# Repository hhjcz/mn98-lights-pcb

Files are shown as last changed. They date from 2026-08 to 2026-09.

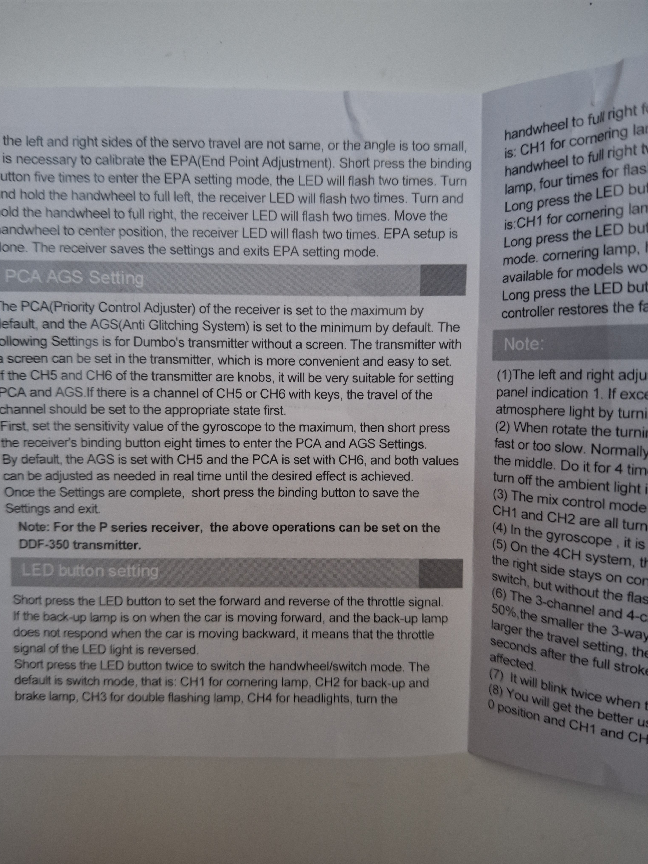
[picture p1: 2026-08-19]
docs/p6dc-led-button-settings-1.jpg

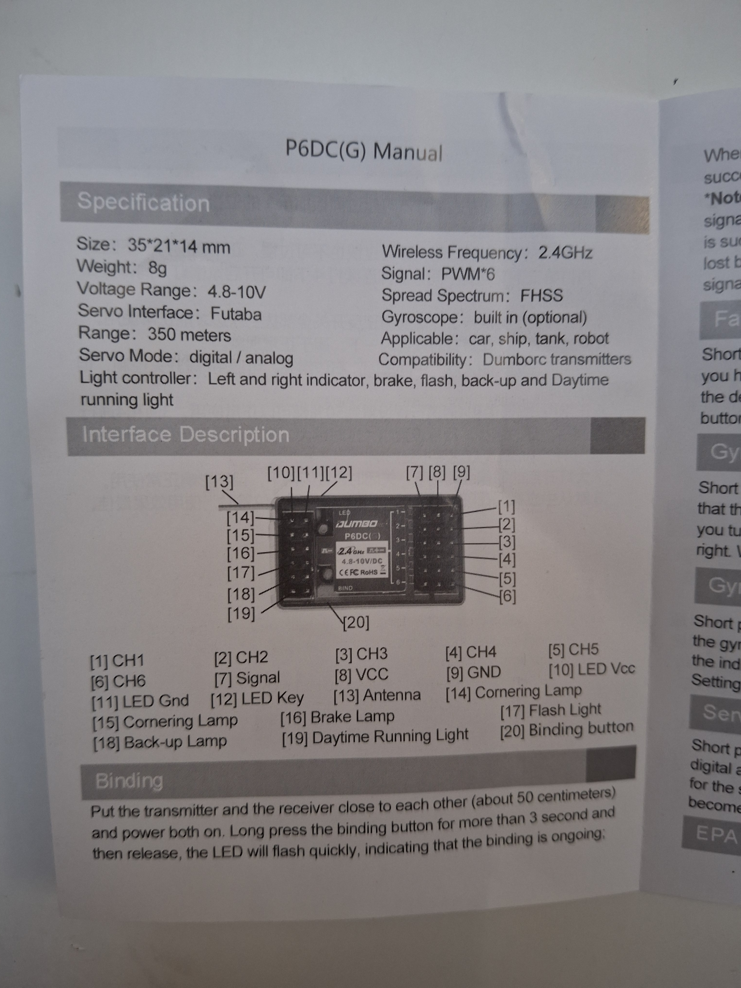
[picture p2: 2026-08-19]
docs/p6dc-interface-description.jpg

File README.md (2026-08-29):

# MN98 Lights PCB

Passive body-light distribution boards for the MN98 RC car and DumboRC P6DC
receiver. The P6DC already controls the LEDs, so variants in this repository
must not add transistors, MOSFETs, resistors, regulators, capacitors, or GND.

## Shared P6DC Interface

The receiver manual is in `docs/`. The light channels follow the P6DC physical
output order: left cornering, right cornering, brake, flash, back-up, and
daytime running light. Any detachable body-to-chassis cable must preserve that
order without crossed conductors.

Before connecting a body harness, confirm LED polarity with a meter. Do not
infer it from wire colours or connector orientation.

## Archived JST-PH Variant

`v1.0-jst-ph/` contains the original JST-PH work-in-progress, including its
KiCad project, Gerbers, PDFs, connector-specific documentation and skill.
It is preserved as a reference and must not be overwritten by the next design.

## Dupont Body Distributor

`pcb-svetla-mn98.kicad_sch` and `pcb-svetla-mn98.kicad_pcb` are the first
compact passive body-side distributor. The current placement candidate is
32 x 36 mm, within the verified 40 x 50 mm maximum envelope. It uses two
merged right-angle 2.54 mm male headers for paired Dupont LEDs. The left header
contains LEFT TURN and DRL. The right header contains RIGHT TURN, BRAKE,
BACK-UP, MARKER, RAMP and SPARE. Both JST-PH body-link connectors exit left so
their harnesses run toward the same chassis location.
All connector courtyards are inside the board outline. Routing is intentionally
deferred until the mechanical placement and JST-PH orientation are approved.
The JST-PH courtyards are inset 2.5 mm from the left edge to protect the
connectors and leave board material around their through-hole pads.

| Header | Physical pairs, top to bottom |
| --- | --- |
| J1, 1x4 | `COMMON+ / LEFT`, `COMMON+ / DRL` |
| J2, 1x12 | `COMMON+ / RIGHT`, `COMMON+ / BRAKE`, `COMMON+ / BACK-UP`, `COMMON+ / MARKER`, `COMMON+ / RAMP`, `COMMON+ / SPARE` |

JP1, JP2 and JP3 select `DRL` or `FLASH` respectively for MARKER, RAMP and
SPARE. Fit the shunt across pins 1-2 for DRL, or 2-3 for FLASH. All right-angle
connectors face outward from the board. The headers are intentionally unkeyed:
silkscreen marks the common-positive side of every pair. Confirm the supplied
LED pair polarity before connecting power.

### Body Link

The detachable body link uses two right-angle JST-PH 1x4 THT connectors. Pin 1
is `COMMON+` on both connectors, so swapping cables A and B cannot connect a
signal output to common positive; it only exchanges light functions.

| Connector | Pin 1 | Pin 2 | Pin 3 | Pin 4 |
| --- | --- | --- | --- | --- |
| J14, link A | `COMMON+` | `LEFT` | `RIGHT` | `BRAKE` |
| J15, link B | `COMMON+` | `FLASH` | `BACK-UP` | `DRL` |

Use pin-to-pin female-female harnesses. A practical custom-length harness can
be made from two pre-crimped JST-PH 4-pin pigtails joined wire-for-wire. Verify
continuity and pin order with a meter before connecting the receiver.

### Planned P6DC Adapter

A second passive PCB will plug into the six 2-pin P6DC light outputs through a
2x6 Dupont female socket and expose matching J14/J15 JST-PH connectors. It
will join the P6DC common-positive pins and preserve the pinout above. The
adapter is intentionally deferred until its fit against the receiver has been
measured. Both designs may later share one customer-panel PCB for fabrication.

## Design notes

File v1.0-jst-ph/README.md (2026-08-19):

# MN98 light distribution PCB

Passive 30 x 40 mm, two-layer FR-4 adapter for the MN98 body lighting and
DumboRC P6DC. The board contains no active components and has no GND net.

## Input J14

J14 is an 8-position right-angle JST-PH connector. Pin 1 is marked on the
footprint. P6DC wiring is:

| Pin | Net |
| --- | --- |
| 1 | COMMON+ |
| 2 | COMMON+ |
| 3 | LEFT |
| 4 | RIGHT |
| 5 | BRAKE |
| 6 | FLASH |
| 7 | BACK-UP |
| 8 | DRL |

Pins 1 and 2 are connected to the same 1.2 mm common-positive spine. LED
connector pad 1 is COMMON+ and pad 2 is the controlled P6DC channel.

Pins 3--8 follow the top-to-bottom order of the P6DC light outputs in the
manual: P6DC [14] left cornering, [15] right cornering, [16] brake, [17]
flash, [18] back-up, and [19] daytime running light. Terminate the chassis
cable as J14 pin-to-pin; do not reverse its conductor order between plugs.

## LED outputs

| Connector | Function | Controlled net |
| --- | --- | --- |
| J1 | Left front turn | LEFT |
| J2 | Right front turn | RIGHT |
| J3 | Left rear turn | LEFT |
| J4 | Right rear turn | RIGHT |
| J5 | Spare | FLASH |
| J6 | Left 5 mm headlight | DRL |
| J7 | Left 3 mm marker | MARKER via JP1 |
| J8 | Left rear red | REAR_RED via JP2 |
| J9 | Roof ramp | RAMP via JP3 |
| J10 | Right 5 mm headlight | DRL |
| J11 | Right 3 mm marker | MARKER via JP1 |
| J12 | Right rear red | REAR_RED via JP2 |
| J13 | Spare | DRL |

All J1--J13 are right-angle JST-PH S2B-PH-K footprints.

## Jumper settings

JP1 and JP3 are 1x03 headers. Fit one 2.54 mm shunt between the centre pin
and the selected outside pin.

| Jumper | Left position | Right position |
| --- | --- | --- |
| JP1 | DRL -> MARKER | MARKER -> FLASH |
| JP3 | DRL -> RAMP | RAMP -> FLASH |

JP2 is a 2x03 header. Fit one vertical 2.54 mm shunt in the column labelled
DRL, BRAKE, or BACK-UP to connect that channel to both rear-red connectors.

## Before manufacturing

1. Check that 30 x 40 mm fits the exact available MN98 body cavity.
2. Check the mating housing and the actual pin-1/polarity of every MN98 LED
   lead. Do not infer it from lead colours or connector orientation.
3. Open `pcb-svetla-mn98.kicad_pcb` in KiCad PCB Editor, run DRC, and resolve
   the two JP2 ratsnest indicators before ordering. The generated Gerbers are
   an inspection aid, not a released fabrication package.

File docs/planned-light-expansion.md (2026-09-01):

# Planned Light Expansion

> **DRAFT / UNVERIFIED**
>
> This document records ideas for a possible future revision. It is not the
> electrical specification of the current PCB. Do not update the schematic,
> PCB placement, routing, silkscreen, or manufacturing files from this document
> until the relevant measurements and decisions below are complete.

## Purpose

The current body distributor predates two purchased modules that may simplify
the chassis-to-body connection and add independently controlled auxiliary
lights. This draft preserves the proposed architecture and the assumptions that
must be tested when the modules arrive.

The intended future revision would:

- replace the planned custom P6DC adapter with a purchased six-wire adapter;
- omit the P6DC FLASH output, which is a true strobe function not currently
  needed on the MN98;
- use semantic body-light names instead of names copied from the P6DC manual;
- allow ROOF LIGHT to follow HEADLIGHTS or switch port 1;
- allow FRONT MARKER and SPARE to follow HEADLIGHTS or switch port 2;
- reserve one optional through-hole series-resistor position for each of those
  three outputs;
- remain a passive PCB containing only connectors, copper routing, labels,
  solder-select jumpers, and any explicitly approved series resistors.

The committed 32 x 36 mm placement-only design remains the active design until
this draft is verified and explicitly approved for a new placement revision.

## Purchased Modules

### Six-wire P6DC light adapter

Product page:

<https://www.aliexpress.com/item/1005008835970185.html>

Observed before delivery:

- the body-side connector appears to be a six-pin JST-PH connector;
- the adapter appears to use six conductors and omit FLASH;
- the likely functions are COMMON+, LEFT, RIGHT, TAIL/BRAKE, REVERSE, and
  HEADLIGHTS, but their physical order and polarity are not known.

The connector series, pin 1, conductor order, continuity, and polarity must all
be checked on the delivered part. The listing is not sufficient evidence for
an electrical pinout.

### DumboRC CH3 light controller

Product page:

<https://www.aliexpress.com/item/1005005666804975.html>

Installation video showing the same type of module:

<https://www.youtube.com/watch?v=yQgD09w_WAs>

Video demonstrating the two outputs and seven-state sequence:

<https://www.youtube.com/watch?v=6RompNNfQf8>

Local reference images copied from the product listing:

- [`ddf350-3ch-switch-overview.webp`](ddf350-3ch-switch-overview.webp)
- [`ddf350-3ch-switch-modes.webp`](ddf350-3ch-switch-modes.webp)
- [`ddf350-3ch-switch-jr-input.webp`](ddf350-3ch-switch-jr-input.webp)
- [`ddf350-3ch-switch-dimensions.webp`](ddf350-3ch-switch-dimensions.webp)
- [`ddf350-3ch-switch-output.webp`](ddf350-3ch-switch-output.webp)
- [`ddf350-3ch-switch-angle.webp`](ddf350-3ch-switch-angle.webp)

The listing calls this a `3CH LED Light Controller`, while the installation
video calls it a `Ch3 Light Control Module`. The latter interpretation is much
more consistent with the visible wiring: the controller is intended for the
receiver's CH3 output rather than providing three independently controlled LED
channels.

The listing and video show:

- one three-wire female JR receiver lead;
- one four-pin 2.54 mm male output, apparently arranged as two 2-pin LED ports;
- an approximately 24 x 10 mm controller body;
- approximately 120 mm overall length including the receiver lead;
- advertised on, off, breathing, and flashing effects.

The second video provides stronger evidence that the four pins are two
separately controlled 2-pin LED outputs:

```text
SWITCH PORT 1: + / -
SWITCH PORT 2: + / -
```

The ports are not fully independent because one receiver input cycles through a
fixed sequence, but the sequence can activate port 1 alone, port 2 alone, or
both ports. Treat them as `SW1+ / SW1-` and `SW2+ / SW2-`. Neither physical pin
order nor the electrical topology is verified on the delivered unit. The
photographs and videos must not be used as the final pinout. The controller may
use low-side switching, protection components, current regulation, or a supply
path that makes either positive output unsuitable for direct connection to
P6DC COMMON+.

The module has one PWM receiver input. The demonstrated controller advances
through seven output states when that input is clicked:

| State | Port 1 | Port 2 |
| --- | --- | --- |
| 1 | steady | off |
| 2 | slow pulse | off |
| 3 | off | steady |
| 4 | off | slow pulse |
| 5 | steady | steady |
| 6 | slow pulse | slow pulse |
| 7 | random flashing | random flashing |

The delivered unit must still be tested because firmware variants may use a
different order or behaviour.

## Proposed Light Names

Future PCB silkscreen should use the function on the vehicle:

| PCB label | Intended function | Probable source |
| --- | --- | --- |
| `LEFT TURN` | Left indicators | P6DC left output |
| `RIGHT TURN` | Right indicators | P6DC right output |
| `HEADLIGHTS` | Main front lights | P6DC DRL output |
| `TAIL / BRAKE` | Rear low-intensity tail and high-intensity brake | P6DC brake output |
| `REVERSE` | Reverse lights | P6DC back-up output |
| `FRONT MARKER` | Front marker lights | HEADLIGHTS or switch port 2 |
| `ROOF LIGHT` | Roof light bar | HEADLIGHTS or switch port 1 |
| `SPARE` | Future auxiliary light | HEADLIGHTS or switch port 2 |

The probable P6DC mapping is based on observed behaviour discussed during
planning. It must be checked across every P6DC light mode before becoming part
of the schematic specification.

## Preferred Electrical Architecture

The preferred architecture assumes that the P6DC light common positive,
receiver supply positive, switch port 1 positive, and switch port 2 positive
are the same electrical rail.

```text
Purchased P6DC adapter, 6 wires
  COMMON+ ----------------------+---------------- standard light positives
  LEFT -------------------------+---------------- LEFT TURN negative
  RIGHT ------------------------+---------------- RIGHT TURN negative
  TAIL/BRAKE -------------------+---------------- TAIL / BRAKE negative
  REVERSE ----------------------+---------------- REVERSE negative
  HEADLIGHTS -------------------+---------------- HEADLIGHTS negative
                                |
CH3 switch, two output ports    |
  SW1+ -------------------------+  only if verified as the same rail
  SW1- ---------------------------- roof selector
  SW2+ -------------------------+  only if verified as the same rail
  SW2- --------+------------------- marker selector
                +------------------- spare selector
```

With a verified shared positive rail, only the switched negative conductor of
each optional light needs selection:

```text
ROOF +   ------------------------------ COMMON+
ROOF -   -- R_ROOF -- [ HEADLIGHTS- | SW1- ]

MARKER + ------------------------------ COMMON+
MARKER - -- R_MARKER -- [ HEADLIGHTS- | SW2- ]

SPARE +  ------------------------------ COMMON+
SPARE -  -- R_SPARE -- [ HEADLIGHTS- | SW2- ]
```

This gives the following intended configurations:

| Output | Default or simple source | Alternate switch source |
| --- | --- | --- |
| `ROOF LIGHT` | `HEADLIGHTS` | `SWITCH PORT 1` |
| `FRONT MARKER` | `HEADLIGHTS` | `SWITCH PORT 2` |
| `SPARE` | `HEADLIGHTS` | `SWITCH PORT 2` |

FRONT MARKER and SPARE operate together when both select switch port 2. Their
combined current must remain within port 2's measured safe capacity. ROOF LIGHT
uses port 1 and can be activated separately in the demonstrated sequence.

TAIL/BRAKE is intentionally not a proposed FRONT MARKER source. Connecting the
front markers to that output would make them change intensity when braking,
which is not the intended vehicle behaviour.

Each three-pad selector must have unambiguous silkscreen showing the two valid
bridges. Simultaneously bridging both sides would connect two controlled
outputs and must be treated as an invalid configuration.

## Safe Fallback Architecture

If the two positive outputs are not proven to be the same rail, do not connect
them. ROOF LIGHT, FRONT MARKER, and SPARE must then use two-pole source
selection so both LED conductors move together between sources.

```text
HEADLIGHTS +  [ ]-[ ROOF + ]-[ ]  SW1+
HEADLIGHTS -  [ ]-[ ROOF - ]-[ ]  SW1-

HEADLIGHTS +  [ ]-[ MARKER + ]-[ ] SW2+
HEADLIGHTS -  [ ]-[ MARKER - ]-[ ] SW2-

HEADLIGHTS +  [ ]-[ SPARE + ]-[ ]  SW2+
HEADLIGHTS -  [ ]-[ SPARE - ]-[ ]  SW2-
```

This fallback needs six three-pad solder selectors instead of three. Both rows
for one light must always be set to the same side. Crossed or double-bridged
settings are invalid and could connect the P6DC and switch outputs together.
The corresponding `R_ROOF`, `R_MARKER`, or `R_SPARE` position remains in series
with each load after its two-pole selector.

The fallback remains the required design assumption until the common-positive
tests pass.

## Optional Series Resistors

The controller's 5-6 V open-circuit output does not prove whether it includes
LED current regulation. Do not add a resistor value based on that voltage
alone. Measure the output current-versus-load characteristic and inspect each
light assembly for an existing resistor.

The proposed PCB should nevertheless reserve three independent horizontal THT
positions:

```text
Resistor_THT:R_Axial_DIN0207_L6.3mm_D2.5mm_P10.16mm_Horizontal
```

| Position | Load |
| --- | --- |
| `R_ROOF` | ROOF LIGHT |
| `R_MARKER` | FRONT MARKER |
| `R_SPARE` | SPARE |

Fit a calculated resistor only when the selected light and source require it.
Fit a 0-ohm THT link or insulated wire link when current limiting already exists
in the controller or light assembly. An unused output may remain open.

FRONT MARKER and SPARE need separate resistor positions even though they share
switch port 2. A single resistor before the split would make their brightness
and current depend on whether one or both loads are connected.

Adding these optional resistors would intentionally revise the current project
rule that prohibits resistors. Do not change the skill or active schematic
until measurements show that the positions are useful and this scope change is
explicitly approved.

## Connector Plan

The connector plan is provisional:

- one six-pin JST-PH input for the purchased P6DC light adapter, subject to
  physical connector and pinout verification;
- one 1x4 2.54 mm female Dupont socket for the CH3 switch's two separate
  2-pin output ports;
- existing unkeyed two-pin Dupont body-light outputs with a visible `+` mark.

The switch can potentially plug directly into the PCB socket. Placement must
reserve clearance for its approximately 24 x 10 mm body, heat-shrink sleeve,
and receiver cable. Direct mounting must not use the switch pins as the only
mechanical support where vibration can fatigue them.

An alternative is a short four-wire extension. In that case the PCB connector
gender depends on the selected cable, so the final footprint should not be
chosen before deciding whether the module is direct-mounted or cable-mounted.

## DDF-350 Control Plan

The CH3 switch should connect to one unused P6DC receiver channel. The DDF-350
must generate whatever single-channel PWM command sequence the module expects.

Possible behaviours include:

- a short transition to an endpoint acting as a button press;
- sequential state changes on repeated button transitions;
- the seven-state sequence documented above;
- a different sequence in another firmware revision.

The ports are separately addressable only through the controller's fixed state
sequence; they are not two freely assignable receiver channels. Transmitter
buttons, switches, endpoints, and mixes should be configured only after
recording the delivered controller's actual state machine.

## Verification Procedure

### Safety

- Perform resistance and continuity measurements only with all power removed.
- Start powered tests with a current-limited supply where practical.
- Do not connect the two candidate positive rails together merely to test
  whether they are compatible.
- Test with inexpensive LEDs or an appropriate dummy load before connecting
  the vehicle light sets.
- Verify every unkeyed connector orientation and LED polarity with a meter.

### Six-wire adapter pinout

Record the actual pin numbering from the connector's mating face, not from the
cable side.

| Pin | Wire colour | P6DC connection | Measured function | Verified |
| --- | --- | --- | --- | --- |
| 1 | TBD | TBD | TBD | no |
| 2 | TBD | TBD | TBD | no |
| 3 | TBD | TBD | TBD | no |
| 4 | TBD | TBD | TBD | no |
| 5 | TBD | TBD | TBD | no |
| 6 | TBD | TBD | TBD | no |

Confirm that FLASH is absent rather than silently combined with another
function.

### CH3 switch pinout

Record pin order from a clearly identified end of the four-pin header.

| Pin | PCB marking | Continuity | Observed output | Verified |
| --- | --- | --- | --- | --- |
| 1 | TBD | TBD | TBD | no |
| 2 | TBD | TBD | TBD | no |
| 3 | TBD | TBD | TBD | no |
| 4 | TBD | TBD | TBD | no |

Check the JR lead separately:

| JR conductor | Expected role | Verified role |
| --- | --- | --- |
| Black | GND | TBD |
| Red | Receiver supply positive | TBD |
| White | PWM signal | TBD |

### Common-positive decision gate

The preferred single-pole selectors are allowed only after all of these checks
pass:

1. Both switch output positives have near-zero resistance to JR red with the
   module unpowered.
2. The two switch output positives have near-zero resistance to each other.
3. P6DC light COMMON+ has near-zero resistance to receiver supply positive with
   the receiver unpowered.
4. All candidate positives measure the same voltage relative to receiver GND
   when powered.
5. The voltage difference remains negligible under representative LED load and
   in every relevant light mode.
6. No diode, regulator, current limiter, or protected output separates any
   positive from the receiver supply rail.
7. Supplying one connection cannot back-power a module through an output in an
   undocumented way.

If any check fails or remains ambiguous, use the two-pole fallback and keep the
positive rails separate.

### Switch behaviour matrix

First record the state after power-up and after signal loss. Then test stable
endpoint positions, short endpoint pulses, repeated pulses, and held commands.

| Input action or state | Port 1 | Port 2 | Persists after neutral | Notes |
| --- | --- | --- | --- | --- |
| Power on | TBD | TBD | TBD | |
| First click | expected steady | expected off | TBD | |
| Second click | expected slow pulse | expected off | TBD | |
| Third click | expected off | expected steady | TBD | |
| Fourth click | expected off | expected slow pulse | TBD | |
| Fifth click | expected steady | expected steady | TBD | |
| Sixth click | expected slow pulse | expected slow pulse | TBD | |
| Seventh click | expected random flash | expected random flash | TBD | |
| PWM signal removed | TBD | TBD | TBD | |
| Power cycled | TBD | TBD | TBD | |

Identify steady on, steady off, breathing, flashing, and any sequence
dependency. Confirm which states operate only one port and whether the previous
state is retained after a power cycle.

### Switch current-limiting test

Test each port separately in its steady-on state using known resistive loads.
Start with a high resistance and decrease it cautiously while recording voltage
and calculated current. Do not short the output.

| Load | Voltage | Calculated current | Port | Notes |
| --- | --- | --- | --- | --- |
| 1 kohm | TBD | TBD | TBD | |
| 470 ohm | TBD | TBD | TBD | |
| 330 ohm | TBD | TBD | TBD | |
| 220 ohm | TBD | TBD | TBD | only if earlier results are safe |

Open-circuit voltage is not evidence of current regulation. A useful LED
current source should show a safe, repeatable current plateau; a high-current
short-circuit protection threshold is not a substitute for LED current
regulation.

## Placement Deferred

A local 40 x 44 mm placement experiment confirmed that the planned connectors,
three vertical 1/4 W THT resistor footprints, and three low-profile solder
selectors can fit within the verified 40 x 50 mm envelope without routing. It
is not an approved placement and should not be committed as the next board
revision.

The current preferred connector directions for the next experiment are:

- J3, the six-pin JST-PH adapter input, should face and exit toward the left;
- J4, the right-angle 1x4 female switch socket, should sit at the bottom board
  edge and allow the switch module or its cable to extend downward;
- LEFT TURN and HEADLIGHTS Dupont pairs should remain accessible from the left;
- the other six Dupont pairs should remain accessible from the right.

Final placement is deferred until the available body volume is measured. The
MN98 shock mounts, structural braces, body posts, windows, interior parts, and
cable bend radii may all constrain the PCB outline and connector exits. The
active schematic should also remain unchanged because both purchased module
pinouts are unverified.

## Mechanical Checks

Before revising placement:

- measure the delivered six-pin adapter plug and its cable exit;
- measure the four-pin switch header pitch, pin length, and pin orientation;
- measure the switch body including heat shrink rather than relying on the
  advertised 24 x 10 mm PCB dimensions;
- decide whether the switch mounts directly to the body PCB or through an
  extension cable;
- map the positions and required clearance of the shock mounts, structural
  braces, body posts, windows, and interior parts;
- check insertion, removal, connector access, and cable bend clearance against
  that obstacle map;
- retain the verified maximum 40 x 50 mm PCB envelope;
- keep complete connector courtyards inside the outline where practical.

## Approval Gates

No active design files should change until the electrical measurements above
are recorded and the following decisions are explicit:

1. Final six-pin adapter pinout and orientation.
2. Final four-pin switch pinout and mounting method.
3. Shared-positive or isolated-positive architecture.
4. Usable CH3 switch sequence and behaviour of both output ports.
5. Confirmation of port 1 for ROOF LIGHT and port 2 for FRONT MARKER and SPARE.
6. Decision whether the three optional THT resistor positions are required.
7. Final selector defaults and silkscreen labels.

After approval, the project must return to the placement workflow:

1. Update the schematic and placement generator without tracks.
2. Generate a placement-only PCB and review outline, connectors, orientation,
   cable exits, switch clearance, and labels.
3. Route only after the new placement is explicitly approved.
4. Run ERC, DRC, netlist, visual, and fabrication-output checks before Gerbers.

## Current Open Questions

- What is the exact six-wire adapter pin order?
- Is its connector definitely JST-PH and which side presents pin 1?
- Is P6DC DRL the preferred HEADLIGHTS behaviour in every configured mode?
- Is P6DC BRAKE consistently low-intensity tail plus high-intensity brake?
- What is the exact four-pin switch output order?
- What is the `+ / -` order of each switch output pair?
- Are P6DC COMMON+, receiver positive, SW1+, and SW2+ one electrical rail?
- Does the delivered module follow the demonstrated seven-state sequence?
- Which button or mix configuration should the DDF-350 use to advance it?
- Should the switch plug directly into the PCB or use an extension harness?
- Does either switch port provide suitable LED current regulation?
- What current can each switch port safely drive?
- Do the actual roof, marker, and spare light assemblies contain resistors?
- What should happen to ROOF LIGHT, FRONT MARKER, and SPARE when the switch is
  absent?

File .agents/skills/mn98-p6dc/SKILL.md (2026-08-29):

---
name: mn98-p6dc
description: Use when designing or reviewing any MN98 body-light PCB that connects to a DumboRC P6DC receiver, including connector selection, P6DC pin order, cable harnesses, LED polarity, or passive routing.
---

# MN98 DumboRC P6DC Light Interface

## Scope

The P6DC controls all light channels. The PCB is a passive body-side harness
adapter only: connectors, routing, labels, and optional selection jumpers are
allowed. Do not add GND, resistors, MOSFETs, transistors, capacitors,
regulators, or other active electronics.

## P6DC Light Order

The P6DC manual is in `docs/`. Its physical light-output order is:

1. Left cornering light
2. Right cornering light
3. Brake
4. Flash
5. Back-up
6. Daytime running light (DRL)

When using an eight-wire body-to-chassis harness with duplicated common
positive, use this order: `COMMON+`, `COMMON+`, `LEFT`, `RIGHT`, `BRAKE`,
`FLASH`, `BACK-UP`, `DRL`. Wire mating connectors pin-to-pin without reversing
the conductor order.

## Required Checks

- Verify the physical connector, pin 1 orientation, and cable order at both
  ends before applying power.
- Verify LED polarity with a meter; lead colours and unkeyed Dupont housings
  are not reliable polarity indicators.
- If a prewired LED pair shares one two-pin connector, both LEDs must use the
  same P6DC channel. Left and right turn signals need separate pairs.
- Use a wide common-positive route and adequate track width for each channel.
- Run ERC, DRC and a visual review before producing Gerbers.

## Required Design Workflow

For every new PCB or substantial connector-layout revision, work in these
separate approval stages:

1. Place footprints and define the board outline without routing tracks.
2. Review and approve dimensions, connector orientation, cable exits,
   clearances, and mechanical fit.
3. Route the PCB only after the placement and outline have been explicitly
   approved.

Do not combine initial placement and routing in one revision. If placement
changes after routing, return to the placement-review stage before rerouting.

## Variants

`v1.0-jst-ph/` is an archived JST-PH design. Do not alter it while creating a
new connector variant. Connector-specific design rules belong in that new
variant's own skill or README.

## Current Dupont Body Distributor

The active root-project design is the passive body-side distributor. Treat the
following as current requirements until explicitly revised:

- Maximum verified PCB envelope: 40 x 50 mm.
- Keep the board as small as practical and keep complete connector courtyards
  inside the outline where possible.
- Current placement candidate: 32 x 36 mm, with no routing until approved.
- Use two merged right-angle 2.54 mm Dupont output headers:
  - Left J1, 1x4: `COMMON+ / LEFT`, `COMMON+ / DRL`.
  - Right J2, 1x12: `COMMON+ / RIGHT`, `COMMON+ / BRAKE`,
    `COMMON+ / BACK-UP`, `COMMON+ / MARKER`, `COMMON+ / RAMP`,
    `COMMON+ / SPARE`.
- Left and right turn-light cables must exit the corresponding body side.
- Use two right-angle JST-PH 1x4 THT body-link connectors on the same side of
  the board so both harnesses run toward the same chassis location:
  - Link A / J14: pin 1 `COMMON+`, pin 2 `LEFT`, pin 3 `RIGHT`, pin 4 `BRAKE`.
  - Link B / J15: pin 1 `COMMON+`, pin 2 `FLASH`, pin 3 `BACK-UP`, pin 4 `DRL`.
- Keeping `COMMON+` on pin 1 of both links makes an A/B cable swap non-critical:
  it exchanges light functions but does not put a signal on the common pin.
- Custom-length body-link cables may be made by joining two pre-crimped 4-pin
  JST-PH pigtails pin-to-pin. Verify continuity before use.
- Keep JP1-JP3 as 2.54 mm 1x3 THT selector headers for now. Low-profile headers
  and shunts may be fitted without changing the footprint.
- Do not add jumper descriptions during placement review; add them after the
  connector layout is approved.
- Top silkscreen must prioritize explicit light-port names and a visible `+`
  for each unkeyed Dupont pair. Omit group titles such as MAIN, AUX, and TURN.
  The body-link connectors only need clear matching labels `A` and `B`.

## Planned P6DC Adapter

A second passive PCB is planned but not yet designed. It will plug into the six
2-pin P6DC light outputs with a 2x6 Dupont female socket and expose matching
JST-PH links A and B. It must preserve the body-link pinout above, join only
the P6DC common-positive pins, and contain no active components or GND. The two
PCB designs may later be placed on one customer panel for fabrication, but the
adapter must first go through the placement-review-routing workflow.

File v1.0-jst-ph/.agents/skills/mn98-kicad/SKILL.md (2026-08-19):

---
name: mn98-kicad
description: Use when editing the MN98 DumboRC P6DC light-distribution KiCad PCB, its schematic, routing, connector assignment, jumper selection, DRC, or manufacturing outputs.
---

# MN98 Light Distribution PCB

## Scope

This board is a passive body-side lighting adapter for an MN98 RC car and a
DumboRC P6DC receiver. It contains connectors, copper routing, labels, and
configuration jumpers only. Do not add resistors, transistors, MOSFETs,
capacitors, regulators, or any GND connection.

The current files are `pcb-svetla-mn98.kicad_pcb`,
`pcb-svetla-mn98.kicad_sch`, and `generate_pcb.py`. Regenerate the board with
`/usr/bin/python3 generate_pcb.py` after changing the generator.

## P6DC Input

J14 is an eight-position right-angle JST-PH connector:

| Pin | Net |
| --- | --- |
| 1 | COMMON+ |
| 2 | COMMON+ |
| 3 | LEFT |
| 4 | RIGHT |
| 5 | BRAKE |
| 6 | FLASH |
| 7 | BACK-UP |
| 8 | DRL |

Pins 1 and 2 must be connected together on the PCB. They feed every LED
connector's pad 1 via a wide common-positive spine. There is no ground net:
each LED's pad 2 is its P6DC controlled return/channel.

Pins 3--8 must preserve the top-to-bottom P6DC light-output order [14]--[19]:
left cornering, right cornering, brake, flash, back-up, and DRL. The chassis
cable is a pin-to-pin harness; never reverse its conductor order between plugs.

## Output Assignment

J1 left front turn: LEFT.
J2 right front turn: RIGHT.
J3 left rear turn: LEFT.
J4 right rear turn: RIGHT.
J5 spare: FLASH.
J6/J10 main headlights: DRL.
J7/J11 front marker lights: MARKER through JP1.
J8/J12 rear red lights: REAR_RED through JP2.
J9 roof ramp: RAMP through JP3.
J13 spare: DRL.

Use right-angle JST-PH S2B-PH-K footprints for all LED outputs and the P6DC
input. Keep them around three PCB edges with cable exit facing outward.

## Jumper Requirements

JP1 is a 1x03, 2.54 mm header. Its centre is MARKER; shunt it to DRL or FLASH.

JP2 is a 2x03, 2.54 mm header. One vertical shunt must select exactly one
source, DRL, BRAKE, or BACK-UP, for both rear-red outputs. The three pads on
the output row must be copper-connected as REAR_RED.

JP3 is a 1x03, 2.54 mm header. Its centre is RAMP; shunt it to DRL or FLASH.

## Layout And Release Checks

- Board target size is 30 x 40 mm, two-layer 1.6 mm FR-4.
- Keep the COMMON+ spine at least 1.2 mm wide; use sensible signal widths.
- Do not create a copper zone or net named GND.
- Run KiCad DRC after every routing change and resolve all errors and
  unconnected ratsnest edges before declaring a fabrication release.
- Export Gerbers only after a clean DRC. Treat existing Gerbers as inspection
  artifacts until then.
- Confirm the real available MN98 body space before changing the outline.
- Confirm every existing LED lead's JST-PH pin 1 and electrical polarity with
  a meter. Never infer polarity from wire colour or connector orientation.

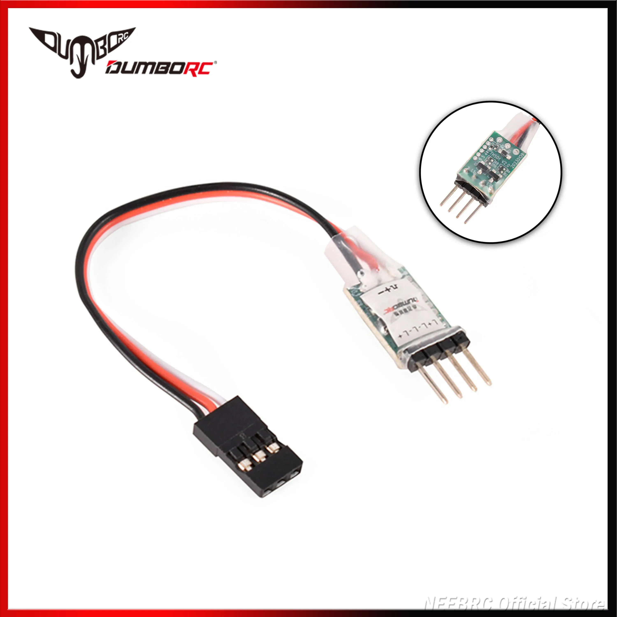
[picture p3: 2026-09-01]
docs/ddf350-3ch-switch-overview.webp

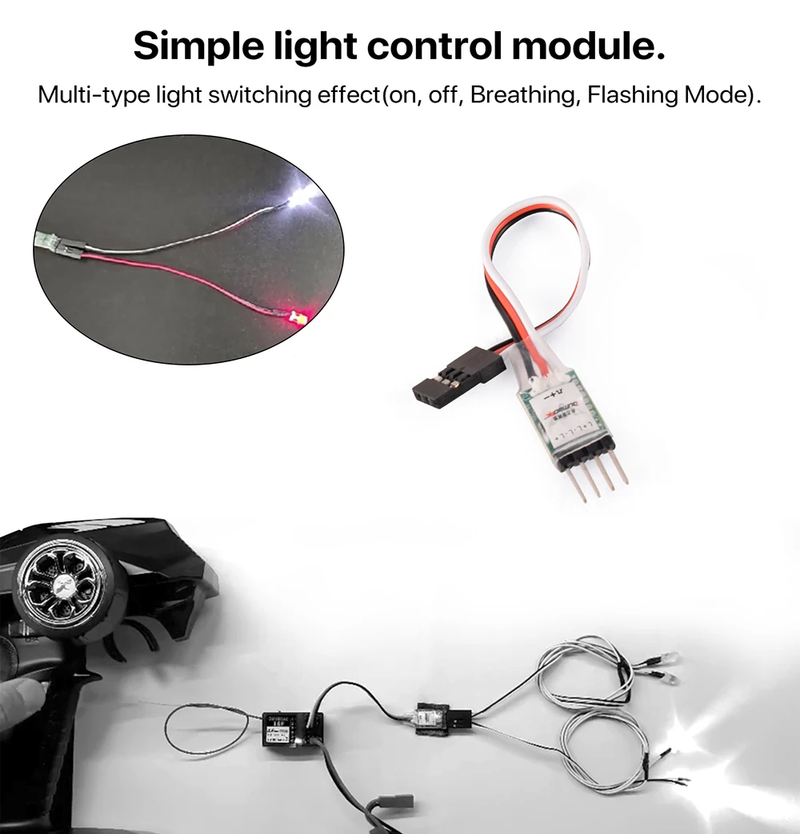
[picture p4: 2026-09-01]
docs/ddf350-3ch-switch-modes.webp

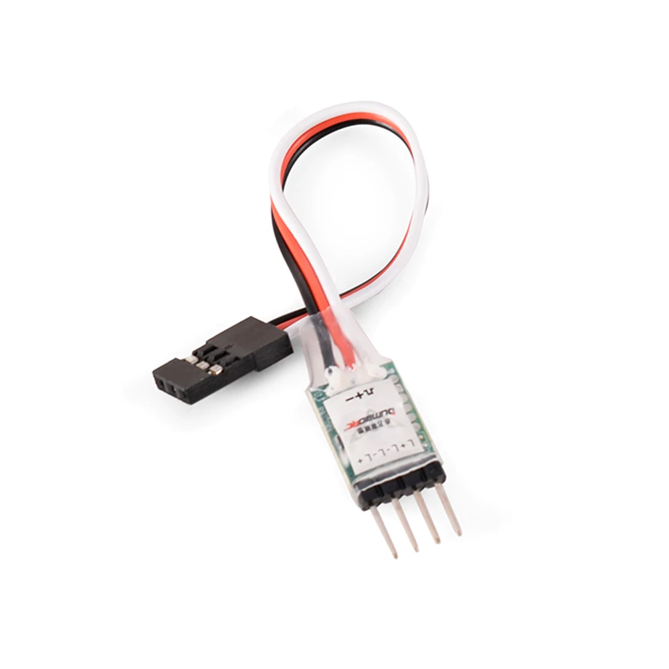
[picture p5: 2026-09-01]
docs/ddf350-3ch-switch-angle.webp

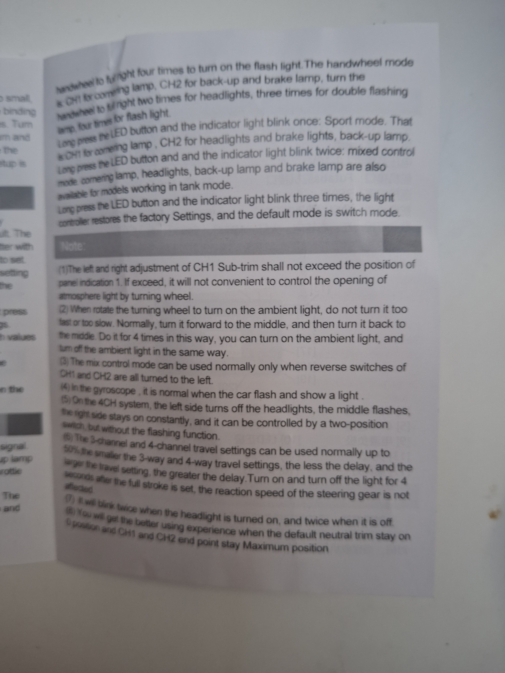
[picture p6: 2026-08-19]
docs/p6dc-led-button-settings-2.jpg

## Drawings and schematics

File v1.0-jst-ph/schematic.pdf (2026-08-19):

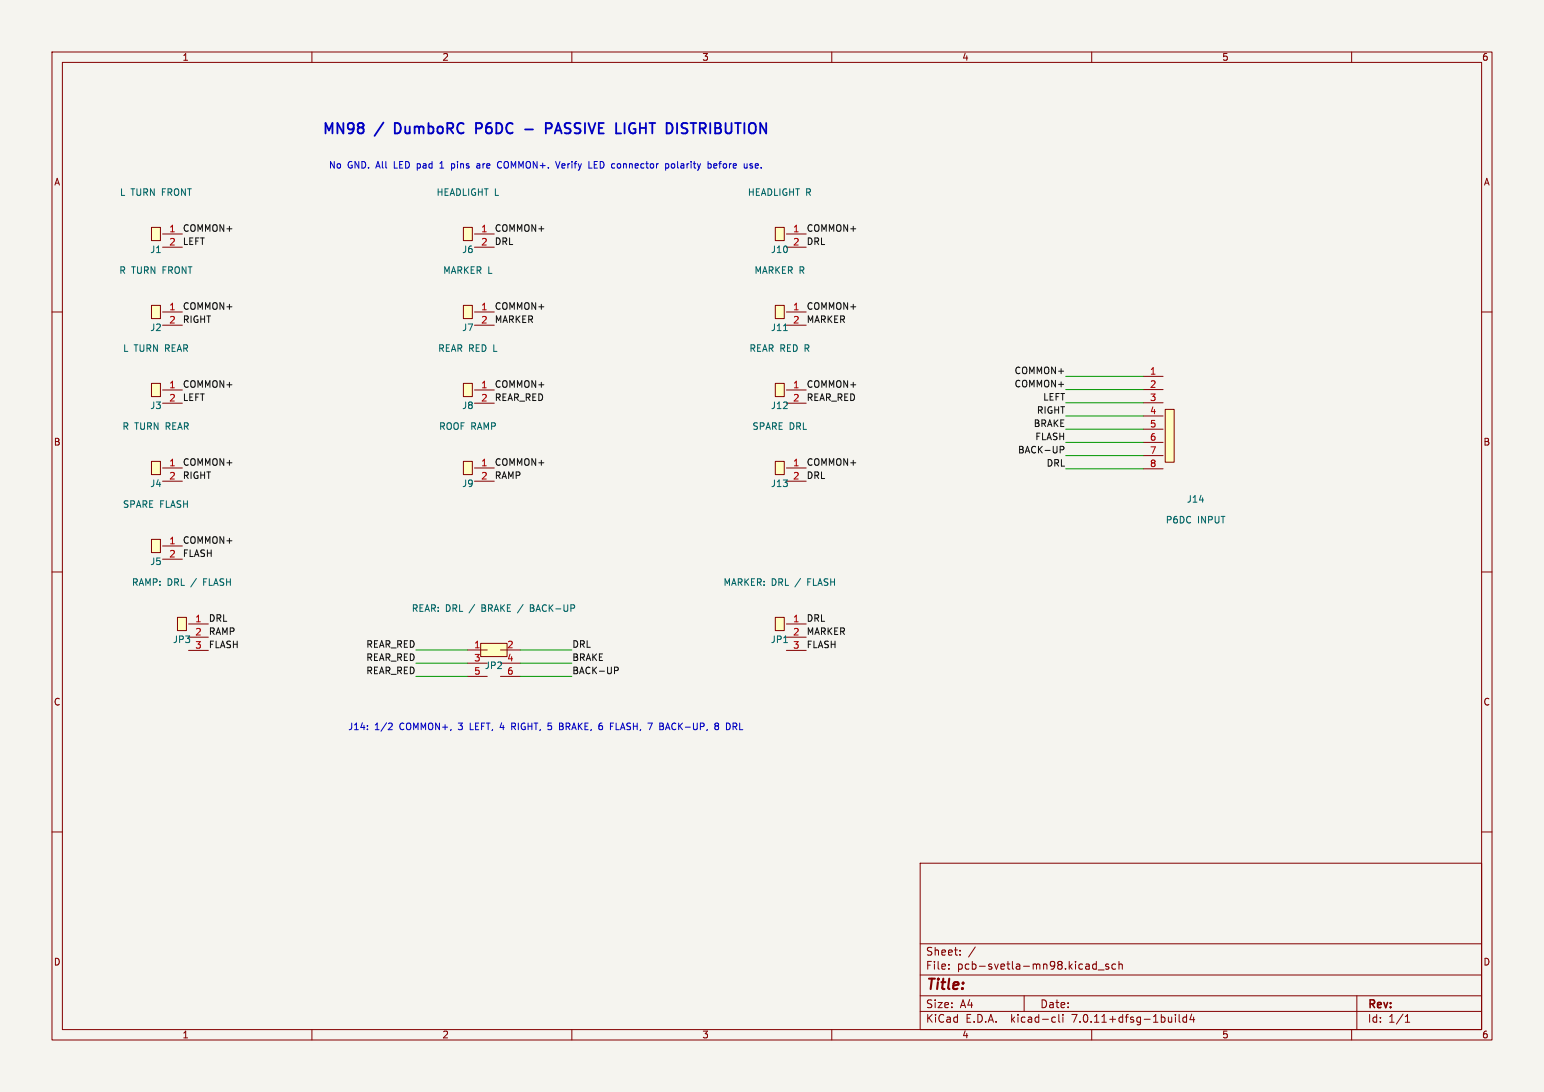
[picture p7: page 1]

JP2 REAR: DRL / BRAKE / BACK-UP

Id: 1/1 Title: File: pcb-svetla-mn98.kicad_sch Sheet: /

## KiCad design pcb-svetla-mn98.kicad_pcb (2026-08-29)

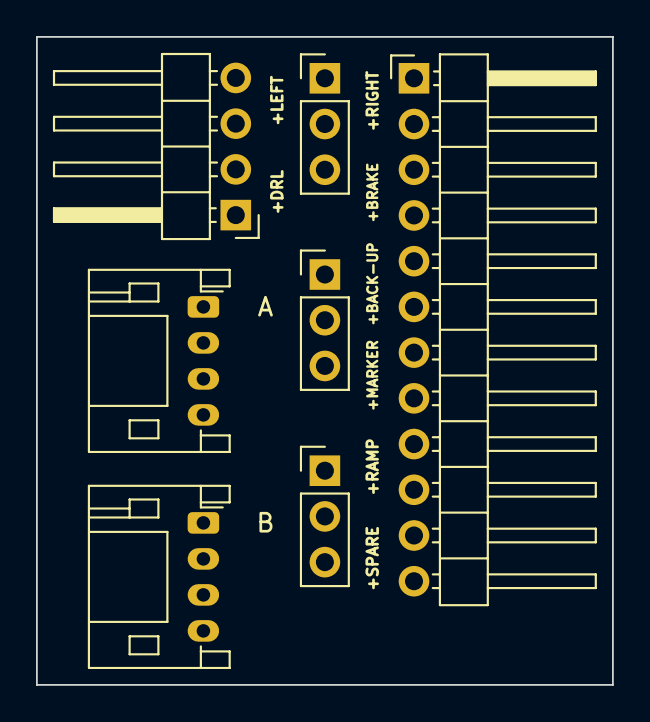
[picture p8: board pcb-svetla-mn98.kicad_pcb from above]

Board: 2 copper layers, 32.0 x 36.0 mm, 7 parts (0 on the bottom side), 10 nets, no tracks yet.

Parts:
J1: LEFT LIGHT PORTS; PinHeader_1x04_P2.54mm_Horizontal
J2: RIGHT LIGHT PORTS; PinHeader_1x12_P2.54mm_Horizontal
J14: BODY LINK A; JST_PH_S4B-PH-K_1x04_P2.00mm_Horizontal
J15: BODY LINK B; JST_PH_S4B-PH-K_1x04_P2.00mm_Horizontal
JP1: MARKER DRL/FLASH; PinHeader_1x03_P2.54mm_Vertical
JP2: RAMP DRL/FLASH; PinHeader_1x03_P2.54mm_Vertical
JP3: SPARE DRL/FLASH; PinHeader_1x03_P2.54mm_Vertical

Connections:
BACK-UP: J2.6, J15.3
BRAKE: J2.4, J14.4
COMMON+: J1.2, J1.4, J2.1, J2.3, J2.5, J2.7, J2.9, J2.11, J14.1, J15.1
DRL: J1.1, J15.4, JP1.1, JP2.1, JP3.1
FLASH: J15.2, JP1.3, JP2.3, JP3.3
LEFT: J1.3, J14.2
MARKER: J2.8, JP1.2
RAMP: J2.10, JP2.2
RIGHT: J2.2, J14.3
SPARE: J2.12, JP3.2

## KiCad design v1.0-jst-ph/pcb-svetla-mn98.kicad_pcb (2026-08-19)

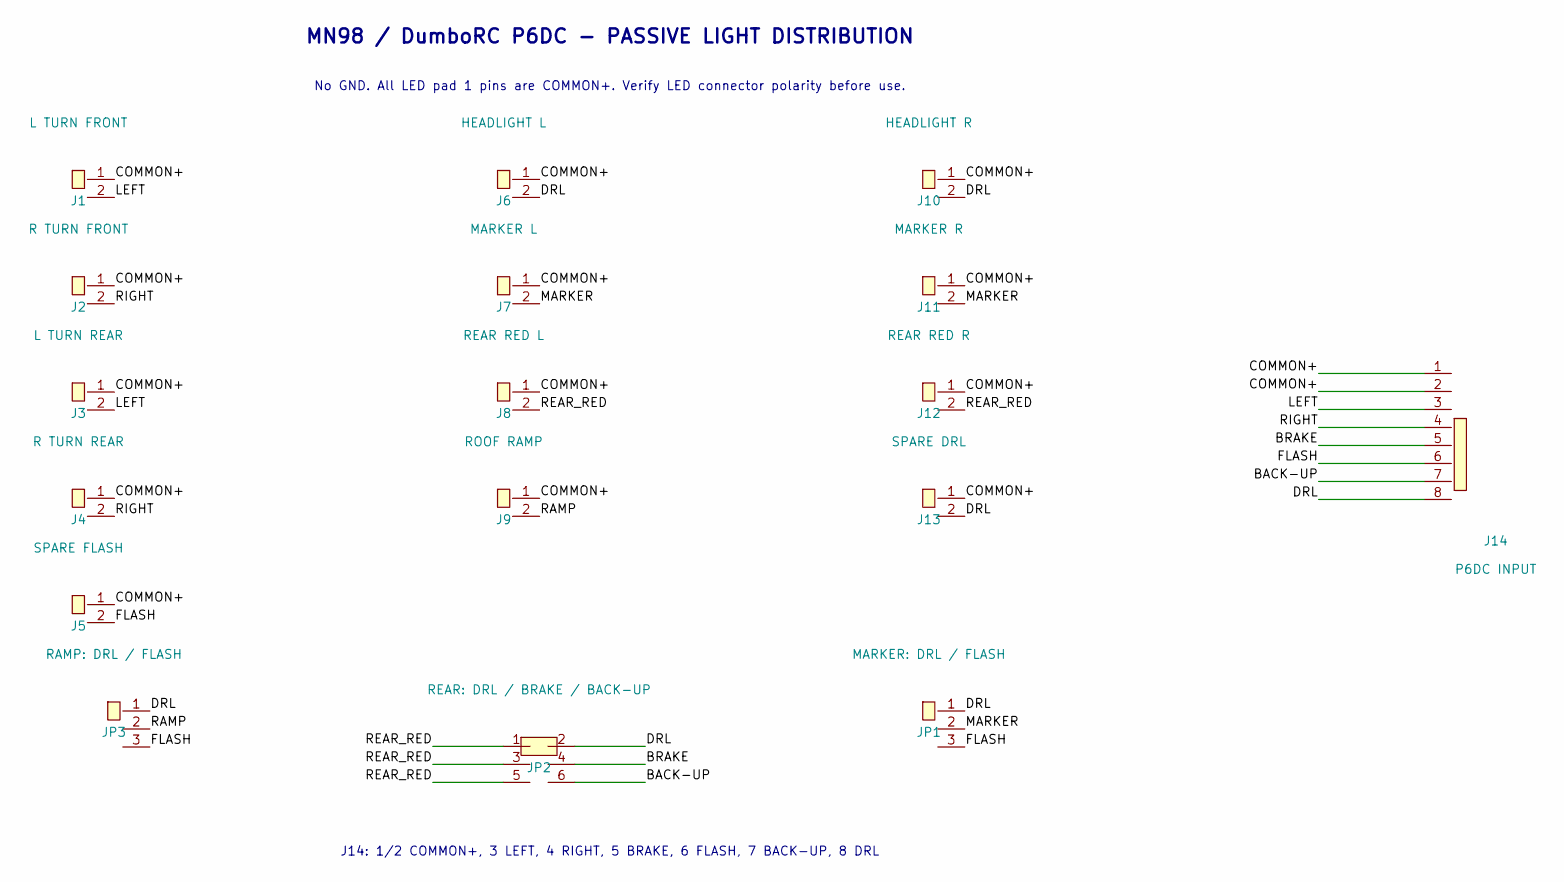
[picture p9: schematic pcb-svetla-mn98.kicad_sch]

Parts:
J1: L TURN FRONT; JST_PH_S2B-PH-K_1x02_P2.00mm_Horizontal
J2: R TURN FRONT; JST_PH_S2B-PH-K_1x02_P2.00mm_Horizontal
J3: L TURN REAR; JST_PH_S2B-PH-K_1x02_P2.00mm_Horizontal
J4: R TURN REAR; JST_PH_S2B-PH-K_1x02_P2.00mm_Horizontal
J5: SPARE FLASH; JST_PH_S2B-PH-K_1x02_P2.00mm_Horizontal
J6: HEADLIGHT L; JST_PH_S2B-PH-K_1x02_P2.00mm_Horizontal
J7: MARKER L; JST_PH_S2B-PH-K_1x02_P2.00mm_Horizontal
J8: REAR RED L; JST_PH_S2B-PH-K_1x02_P2.00mm_Horizontal
J9: ROOF RAMP; JST_PH_S2B-PH-K_1x02_P2.00mm_Horizontal
J10: HEADLIGHT R; JST_PH_S2B-PH-K_1x02_P2.00mm_Horizontal
J11: MARKER R; JST_PH_S2B-PH-K_1x02_P2.00mm_Horizontal
J12: REAR RED R; JST_PH_S2B-PH-K_1x02_P2.00mm_Horizontal
J13: SPARE DRL; JST_PH_S2B-PH-K_1x02_P2.00mm_Horizontal
J14: P6DC INPUT; JST_PH_S8B-PH-K_1x08_P2.00mm_Horizontal
JP1: MARKER: DRL / FLASH; PinHeader_1x03_P2.54mm_Horizontal
JP2: REAR: DRL / BRAKE / BACK-UP; PinHeader_2x03_P2.54mm_Vertical
JP3: RAMP: DRL / FLASH; PinHeader_1x03_P2.54mm_Horizontal

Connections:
/BACK-UP: J14.7, JP2.6
/BRAKE: J14.5, JP2.4
/COMMON+: J1.1, J2.1, J3.1, J4.1, J5.1, J6.1, J7.1, J8.1, J9.1, J10.1, J11.1, J12.1, J13.1, J14.1, J14.2
/DRL: J6.2, J10.2, J13.2, J14.8, JP1.1, JP2.2, JP3.1
/FLASH: J5.2, J14.6, JP1.3, JP3.3
/LEFT: J1.2, J3.2, J14.3
/MARKER: J7.2, J11.2, JP1.2
/RAMP: J9.2, JP3.2
/REAR_RED: J8.2, J12.2, JP2.1, JP2.3, JP2.5
/RIGHT: J2.2, J4.2, J14.4

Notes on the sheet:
MN98 / DumboRC P6DC - PASSIVE LIGHT DISTRIBUTION
No GND. All LED pad 1 pins are COMMON+. Verify LED connector polarity before use.
J14: 1/2 COMMON+, 3 LEFT, 4 RIGHT, 5 BRAKE, 6 FLASH, 7 BACK-UP, 8 DRL

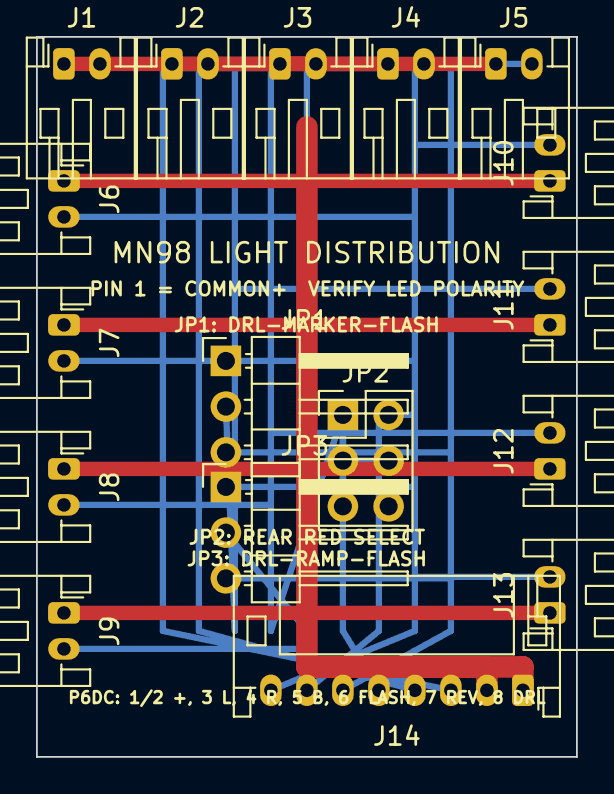
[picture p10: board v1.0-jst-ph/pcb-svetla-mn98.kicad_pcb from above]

Board: 2 copper layers, 30.0 x 40.0 mm, 17 parts (0 on the bottom side), 10 nets.

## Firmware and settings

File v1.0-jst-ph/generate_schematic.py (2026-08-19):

#!/usr/bin/env python3
"""Generate the MN98 passive light-distribution schematic from scratch."""

from pathlib import Path
from uuid import NAMESPACE_URL, uuid4, uuid5


ROOT = Path(__file__).resolve().parent
OUT = ROOT / "pcb-svetla-mn98.kicad_sch"


def uid():
    return str(uuid4())


def component_uuid(reference):
    return str(uuid5(NAMESPACE_URL, f"mn98-lights-pcb/schematic/{reference}"))


def prop(name, value, x=0, y=0, hidden=False):
    hide = " hide" if hidden else ""
    return f'''    (property "{name}" "{value}" (at {x} {y} 0)
      (effects (font (size 1.27 1.27)){hide})
    )'''


def connector_lib(name, pins, two_column=False):
    pin_defs = []
    for number, x, y, angle in pins:
        pin_defs.append(f'''        (pin passive line (at {x} {y} {angle}) (length 3.81)
          (name "Pin_{number}" (effects (font (size 1.27 1.27))))
          (number "{number}" (effects (font (size 1.27 1.27))))
        )''')
    width = 2.54 if two_column else 0.86
    return f'''    (symbol "MN98:{name}" (pin_names (offset 1.016) hide) (in_bom yes) (on_board yes)
{prop("Reference", "J", 0, 2.54)}
{prop("Value", name, 0, -5.08)}
{prop("Footprint", "", 0, 0, True)}
{prop("Datasheet", "~", 0, 0, True)}
      (symbol "{name}_1_1"
        (rectangle (start {-width} 1.27) (end {width} {-max(p[2] for p in pins) - 1.27})
          (stroke (width 0.1524) (type default))
          (fill (type background))
        )
{chr(10).join(pin_defs)}
      )
    )'''


LIB_1X2 = connector_lib("Conn_01x02", [("1", 5.08, 0, 180), ("2", 5.08, -2.54, 180)])
LIB_1X3 = connector_lib("Conn_01x03", [("1", 5.08, 0, 180), ("2", 5.08, -2.54, 180), ("3", 5.08, -5.08, 180)])
LIB_1X8 = connector_lib("Conn_01x08", [(str(i), -5.08, 10.16 - i * 2.54, 0) for i in range(1, 9)])
LIB_2X3 = connector_lib(
    "Conn_02x03",
    [("1", -5.08, 0, 0), ("2", 5.08, 0, 180), ("3", -5.08, -2.54, 0),
     ("4", 5.08, -2.54, 180), ("5", -5.08, -5.08, 0), ("6", 5.08, -5.08, 180)],
    two_column=True,
)


def instance(lib_id, reference, value, footprint, x, y, pins, reference_at=None, value_at=None):
    reference_at = reference_at or (x, y + 3)
    value_at = value_at or (x, y - 8)
    lines = [
        f'  (symbol (lib_id "MN98:{lib_id}") (at {x} {y} 0) (unit 1)',
        '    (in_bom yes) (on_board yes) (dnp no)',
        f'    (uuid {component_uuid(reference)})',
        prop("Reference", reference, *reference_at),
        prop("Value", value, *value_at),
        prop("Footprint", footprint, x, y, True),
        prop("Datasheet", "~", x, y, True),
    ]
    lines.extend(f'    (pin "{pin}" (uuid {uid()}))' for pin in pins)
    lines.extend([
        '    (instances',
        '      (project "pcb-svetla-mn98"',
        f'        (path "/{ROOT_UUID}" (reference "{reference}") (unit 1))',
        '      )',
        '    )',
        '  )',
    ])
    return "\n".join(lines)


def label(name, x, y, rotation=0, justify="left"):
    return f'''  (label "{name}" (at {x} {y} {rotation})
    (effects (font (size 1.27 1.27)) (justify {justify} bottom))
    (uuid {uid()})
  )'''


def wire(x1, y1, x2, y2):
    return f'''  (wire (pts (xy {x1} {y1}) (xy {x2} {y2}))
    (stroke (width 0) (type solid))
    (uuid {uid()})
  )'''


ROOT_UUID = str(uuid5(NAMESPACE_URL, "mn98-lights-pcb/schematic/root"))


def add_1x2(items, labels, reference, value, x, y, signal):
    items.append(instance("Conn_01x02", reference, value,
                          "Connector_JST:JST_PH_S2B-PH-K_1x02_P2.00mm_Horizontal", x, y, ("1", "2")))
    # Symbol-local Y is inverted when mapped to the schematic page.
    labels.extend((label("COMMON+", x + 5.08, y), label(signal, x + 5.08, y + 2.54)))


def main():
    items, labels, wires = [], [], []
    outputs = [
        ("J1", "L TURN FRONT", 30, 45, "LEFT"),
        ("J2", "R TURN FRONT", 30, 60, "RIGHT"),
        ("J3", "L TURN REAR", 30, 75, "LEFT"),
        ("J4", "R TURN REAR", 30, 90, "RIGHT"),
        ("J5", "SPARE FLASH", 30, 105, "FLASH"),
        ("J6", "HEADLIGHT L", 90, 45, "DRL"),
        ("J7", "MARKER L", 90, 60, "MARKER"),
        ("J8", "REAR RED L", 90, 75, "REAR_RED"),
        ("J9", "ROOF RAMP", 90, 90, "RAMP"),
        ("J10", "HEADLIGHT R", 150, 45, "DRL"),
        ("J11", "MARKER R", 150, 60, "MARKER"),
        ("J12", "REAR RED R", 150, 75, "REAR_RED"),
        ("J13", "SPARE DRL", 150, 90, "DRL"),
    ]
    for output in outputs:
        add_1x2(items, labels, *output)

    # J14 follows the physical top-to-bottom P6DC output order [14]--[19].
    items.append(instance("Conn_01x08", "J14", "P6DC INPUT",
                          "Connector_JST:JST_PH_S8B-PH-K_1x08_P2.00mm_Horizontal", 225, 80,
                          tuple(str(i) for i in range(1, 9)), reference_at=(230, 96), value_at=(230, 100)))
    for pin, net in enumerate(("COMMON+", "COMMON+", "LEFT", "RIGHT", "BRAKE", "FLASH", "BACK-UP", "DRL"), 1):
        y = 72.38 + (pin - 1) * 2.54
        wires.append(wire(219.92, y, 205, y))
        labels.append(label(net, 205, y, 180, "right"))

    items.append(instance("Conn_01x03", "JP1", "MARKER: DRL / FLASH",
                          "Connector_PinHeader_2.54mm:PinHeader_1x03_P2.54mm_Horizontal", 150, 120,
                          ("1", "2", "3")))
    for pin, net in enumerate(("DRL", "MARKER", "FLASH")):
        labels.append(label(net, 155.08, 120 + pin * 2.54))

    items.append(instance("Conn_02x03", "JP2", "REAR: DRL / BRAKE / BACK-UP",
                          "Connector_PinHeader_2.54mm:PinHeader_2x03_P2.54mm_Vertical", 95, 125,
                          ("1", "2", "3", "4", "5", "6")))
    for pin, net, x, y, side in (("1", "REAR_RED", 89.92, 125, "left"), ("2", "DRL", 100.08, 125, "right"),
                                  ("3", "REAR_RED", 89.92, 127.54, "left"), ("4", "BRAKE", 100.08, 127.54, "right"),
                                  ("5", "REAR_RED", 89.92, 130.08, "left"), ("6", "BACK-UP", 100.08, 130.08, "right")):
        end_x = 80 if side == "left" else 110
        wires.append(wire(x, y, end_x, y))
        labels.append(label(net, end_x, y, 180 if side == "left" else 0, "right" if side == "left" else "left"))

    items.append(instance("Conn_01x03", "JP3", "RAMP: DRL / FLASH",
                          "Connector_PinHeader_2.54mm:PinHeader_1x03_P2.54mm_Horizontal", 35, 120,
                          ("1", "2", "3")))
    for pin, net in enumerate(("DRL", "RAMP", "FLASH")):
        labels.append(label(net, 40.08, 120 + pin * 2.54))
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

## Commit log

2026-08-19 Initial MN98 light distribution PCB
    [pcb-svetla-mn98-B_Courtyard.gbr, pcb-svetla-mn98-B_Cu.gbl, pcb-svetla-mn98-B_Fab.gbr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]
2026-08-19 Align J14 pinout with P6DC outputs
    [pcb-svetla-mn98-B_Courtyard.gbr, pcb-svetla-mn98-B_Cu.gbl, pcb-svetla-mn98-B_Fab.gbr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]
2026-08-19 Keep J14 within board outline
    [pcb-svetla-mn98-B_Courtyard.gbr, pcb-svetla-mn98-B_Cu.gbl, pcb-svetla-mn98-B_Fab.gbr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]
2026-08-19 Add synchronized KiCad schematic
    [pcb-svetla-mn98.kicad_pcb, pcb-svetla-mn98.kicad_sch]
2026-08-20 Archive JST-PH design and prepare Dupont variant
    [pcb-svetla-mn98-B_Courtyard.gbr, pcb-svetla-mn98-B_Cu.gbl, pcb-svetla-mn98-B_Fab.gbr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]
2026-08-20 Add Dupont light distribution PCB
    [pcb-svetla-mn98.kicad_pcb, pcb-svetla-mn98.kicad_sch]
2026-08-26 Add JLCPCB manufacturing files
    [pcb-svetla-mn98-B_Cu.gbr, pcb-svetla-mn98-B_Mask.gbr, pcb-svetla-mn98-B_Silkscreen.gbr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]
2026-08-29 Revise body distributor placement
    [pcb-svetla-mn98-B_Cu.gbr, pcb-svetla-mn98-B_Mask.gbr, pcb-svetla-mn98-B_Silkscreen.gbr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]
2026-09-01 Correct CH3 switch plan
